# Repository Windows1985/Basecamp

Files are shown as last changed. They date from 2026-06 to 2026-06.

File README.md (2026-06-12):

# Basecamp

Basecamp is a passive overnight sleep monitoring system that runs on a Raspberry Pi 4 sitting on a bedside table. It combines WiFi channel state information from two ESP32-S3 nodes, 24GHz mmWave radar, an I2S microphone, and four environmental sensors to estimate sleep quality and produce a personalised recovery score each morning. Nothing touches the body. The system was built to answer a specific question: whether next-day cognitive performance is predictable from raw radio and acoustic signals, and which overnight conditions matter most for a specific person's physiology.

Three sensing modalities work in parallel during the night. Two ESP32-S3 nodes, one on each side of the bed at mattress height, measure how the body disturbs ambient WiFi signals across 56 subcarriers; chest movement during breathing creates measurable phase shifts that the system extracts via bandpass FFT in 30-second windows. A HLK-LD2410C 24GHz mmWave radar tracks bed entry, bed exit, and micro-motion throughout the night but does not output a respiration waveform, so breathing rate comes from CSI and audio only. An INMP441 I2S microphone captures breathing sounds and snoring, and four I2C environmental sensors monitor CO2, VOC, temperature, humidity, and light. The modalities were chosen because they are complementary: CSI measures fine respiratory displacement, radar provides reliable bed presence detection, audio catches acoustic breathing signatures, and environmental sensors capture conditions that affect sleep quality independently of body physiology.

The goal is a personalised recovery model, not a replacement for clinical sleep study. Sleep staging accuracy is approximately 72 to 78 percent across three classes, which is honest rather than competitive with polysomnography. Heart rate from CSI is trend-level and not reliable enough for HRV derivation. What the system does well is measure breathing rate more directly than wrist-based wearables (which infer it from optical heart rate), build a model calibrated to one person's physiology rather than population averages, and run continuously without any contact with the body.

## Hardware

The main components are listed below. See `hardware/bom.md` for the full bill of materials with prices and purchasing notes.

| Component | Quantity | Notes |
|---|---|---|
| Raspberry Pi 4 Model B | 1 | 4GB RAM; runs all daemons and the morning pipeline |
| ESP32-S3-DevKitC-1 N16R8 | 2 | One node each side of the bed at mattress height |
| SanDisk MicroSD 32GB | 1 | Class 10; all data stored locally in SQLite |
| INMP441 | 1 | I2S digital microphone; connected to GPIO 18, 19, 20 |
| HLK-LD2410C | 1 | 24GHz mmWave radar; UART at 256000 baud on hardware UART |
| SHT40 | 1 | Temperature and humidity; I2C address 0x44 |
| BH1750 | 1 | Light sensor; I2C address 0x23 |
| SCD40 | 1 | CO2 sensor; I2C address 0x62; verify chip markings before use |
| SGP40 | 1 | VOC index sensor; I2C address 0x59 |
| 2.8 inch IPS SPI touchscreen | 1 | ILI9341 or ST7789 driver, 240x320 pixels |
| DS3231 RTC module | 1 | Battery-backed real-time clock; maintains timestamps during offline power cycles |

The enclosure is 3D printed in matte black PLA at 96 x 136 x 49mm assembled (pod peak 74mm). The v4 magnetic-lid design lifts off tool-free for daily access; two M3x45 travel screws thread through the rear posts for transport only. Both ESP32 nodes power directly from the Pi's rear USB-A ports (no hub required). Networking uses a hotspot-first architecture: wlan0 runs as an isolated AP for the ESP32 nodes (the WiFi link exists solely because CSI is a property of a WiFi association), and eth0 provides internet and dashboard access. See `hardware/wiring.md` for GPIO assignments, `hardware/bom.md` for the complete component list, and `docs/networking.md` for the wlan0/eth0 architecture.

## Architecture

Three lightweight daemons run overnight on the Pi. The sensor logger reads all I2C environmental sensors every 30 seconds and writes to SQLite. The presence watcher monitors the radar, writes bed entry and exit timestamps, and fires the morning batch job when bed exit is detected after a minimum four-hour sleep duration. The audio chunker processes microphone input in 30-second chunks, classifying each as silence, ambient, or snoring, and stores relevant chunks as Opus files. A separate CSI ingest process receives raw CSI over UDP from the ESP32 nodes and writes cross-subcarrier variance to the database at 20 Hz. Nothing runs during the night beyond lightweight logging; all analysis runs in the morning.

```
hardware/       bill of materials, wiring reference, enclosure STL
firmware/       ESP32 flashing scripts and CSI capture configuration
server/         overnight daemons: sensor logger, presence watcher, audio chunker, sleep mode state machine
pipeline/       morning batch: CSI extraction, feature engineering, staging, scoring, attribution, anomaly detection, report
dashboard/      React web app for sleep and recovery visualisation
morning/        Flask API for daily subjective log (recovery, energy, clarity, mood ratings)
analysis/       Jupyter notebooks for MESA transfer learning and model evaluation
docs/adr/       architecture decision records for every major design choice
docs/build-log/ weekly entries covering what was built, what changed, and what failed
```

## Signal processing

The CSI breathing rate extraction treats the cross-subcarrier variance signal from each ESP32 node as a 20 Hz time series. For each 30-second window (600 samples), the pipeline applies a 4th-order Butterworth bandpass filter from 0.10 to 0.50 Hz, which corresponds to 6 to 30 breaths per minute and covers the full physiological range for sleeping adults. The dominant frequency within that band is extracted via an 8192-point zero-padded FFT, giving a frequency resolution of 0.0024 Hz, which is approximately 0.06 BPM. In synthetic testing against known ground-truth signals, the extraction achieves around plus or minus 0.06 BPM accuracy. Real-world accuracy depends on signal quality, mattress thickness, and sleeping position, and has not yet been measured on real overnight data. Movement power is extracted from the same signal using a complementary high-pass filter above 0.50 Hz.

## Sleep staging

The sleep stage classifier produces three classes: wake, deep sleep, and a combined light and REM class. N1 and N2 are not distinguished because the respiratory and motion differences between them are not detectable from radio or acoustic signals without EEG; any system claiming to separate N1 from N2 using WiFi CSI alone is overclaiming. Wake is detected by movement power above threshold from radar and CSI combined. Deep sleep is characterised by sustained low movement, slow and regular breathing in the 10 to 15 BPM range, and long uninterrupted windows. REM is estimated probabilistically within the light and REM class via breathing irregularity and snoring detection, and is stored as a flag rather than a separate stage. Expected accuracy is around 88 percent for wake, 75 percent for deep sleep, and 65 percent for the combined light and REM class, for an overall three-class accuracy of approximately 72 to 78 percent. These estimates come from the published literature on similar sensor configurations and should be treated as approximate until measured on real data. A Random Forest personalisation layer activates after 14 nights and is trained on heuristic labels, not EEG ground truth. A planned Phase 3 upgrade will pretrain on the MESA Sleep dataset (actigraphy plus PSG annotations) and fine-tune on personal data, which published work suggests improves three-class accuracy by 5 to 8 percentage points.

## Recovery score

The morning recovery score is a weighted composite across four components.

| Component | Weight | What it measures |
|---|---|---|
| Sleep architecture | 40% | Deep sleep proportion, REM estimate, total duration, and sleep efficiency |
| Continuity | 25% | Awakening count, sleep onset latency, and fragmentation |
| Breathing quality | 20% | Breathing regularity, snoring duration, and estimated apnea events |
| Environment | 15% | Peak CO2, VOC index, temperature deviation from optimal, and light intrusion |

The fixed weights reflect published sleep science on which factors most reliably predict next-day cognitive performance. After approximately 30 labelled nights, a regression model replaces the fixed scoring formula and learns weights specific to one person's physiology, using morning ratings across four subjective dimensions: recovery, energy, mental clarity, and mood. SHAP attribution then generates a plain-language explanation of each night's result, identifying which factors drove the score up or down.

## Known limitations

- Concrete walls between the ESP32 nodes and the bed will substantially degrade CSI signal quality; both nodes must be in the same room as the sleep area.
- Heart rate variability cannot be derived from CSI at the accuracy needed for HRV analysis; the system does not attempt HRV measurement.
- No SpO2 measurement is included; oxygen saturation monitoring requires a contact sensor.
- Sleep staging accuracy is limited by the absence of EEG ground truth; the three-class classifier is trained on heuristic labels, not PSG-validated annotations.
- Heart rate from CSI is trend-level only and is not reported as a precise per-beat measurement.
- The Pi's single radio chip cannot simultaneously run as an AP (for the ESP32 nodes) and a station client; internet access requires eth0.
- The personalised recovery predictor requires a minimum of 14 labelled nights before the machine learning layer activates; the fixed-weight model runs until then.
- The SGP40 VOC sensor requires approximately 24 hours of burn-in before its readings are reliable.

## Status

The software pipeline is complete and tested against simulated data. Hardware assembly and first real-world data collection have not yet started. All pipeline unit tests pass with simulated sensor data. No real sleep data has been collected.

## Acknowledgements

Sleep staging transfer learning uses the MESA Sleep dataset from the National Sleep Research Resource. Required acknowledgement: "NSRR R24 HL114473: NHLBI National Sleep Research Resource."

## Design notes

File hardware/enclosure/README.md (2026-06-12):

# Enclosure v4

Parametric CadQuery generator for the Basecamp bedside enclosure. Two-part matte black FDM print: body and lid.

**Final dimensions:** 96 x 136 x 49mm assembled, screen pod peak 74mm.

---

## Files

| File | Description |
|---|---|
| `enclosure_v4.py` | Parametric source of truth. All geometry driven by named constants at the top of the file. Edit here, never in the STEP/STL exports. |
| `basecamp_body_v4.step` | Body STEP for SolidWorks import or direct slicing |
| `basecamp_lid_v4.step` | Lid STEP |
| `basecamp_body_v4.stl` | Body STL for direct upload to print service |
| `basecamp_lid_v4.stl` | Lid STL |
| `validate.py` | Collision and watertightness test suite. Run after any geometry change. |
| `previews/` | Render images: body, lid, assembled (3 views each), 2D cross-sections |
| `archive/v3/` | v3 files retained for the build-log narrative |

---

## Generating the STL/STEP exports

```bash
pip install cadquery
python enclosure_v4.py
# Outputs: basecamp_body_v4.step/.stl, basecamp_lid_v4.step/.stl
```

Run validate.py afterward before sending to the printer:

```bash
pip install trimesh manifold3d
python validate.py
# All checks should print OK
```

---

## Print settings

### Body

- Orientation: flat on the base (no supports needed)
- Layer height: 0.2mm
- Infill: 20% gyroid
- Perimeters: 3 (ensures walls are solid at 3mm)
- Material: matte black PLA or PETG

### Lid

- Orientation: top face down on the build plate
- Supports: required under registration lip, boss columns, and pod interior cavity
- Layer height: 0.15mm for the pod slope (0.2mm acceptable elsewhere)
- Infill: 20% gyroid
- Perimeters: 3
- Material: same material as body -- thermal expansion must match

### Clearances

The design assumes 0.3-0.4mm FDM tolerance. Key mating features:

| Feature | Clearance |
|---|---|
| Registration lip (body seat to lid lip) | 0.25mm per side |
| Chimney plug (lid plug to chimney walls) | 0.40mm per side |
| Magnet boss pocket (body-side recess) | 0.1mm per side |

If the lip binds after printing: sand the outer face of the lid lip with 400-grit, test fit, repeat. Do not sand the body seat.

---

## Magnet assembly procedure

The lid is held by 6 pairs of O6x3 N35 magnets (2 front, 2 rear, 2 mid-side). Body-side magnets sit recessed 0.8mm in wall-boss pockets; lid-side magnets glue in proud 0.8mm so the faces meet flush when the lid seats.

**CHECK POLARITY BEFORE GLUING.**

1. Dry-stack all 12 magnets into their intended pockets without glue.
2. Close the lid and verify it seats and releases cleanly.
3. Open the lid carefully without disturbing the magnets.
4. Mark the same face of each magnet (the face pointing away from the body wall) with a permanent marker.
5. Remove magnets one at a time, apply a small drop of CA glue or epoxy to the pocket, and replace each magnet mark-up on the body side and mark-down on the lid side.
6. Hold each pair in place for 30 seconds before moving to the next.
7. Allow full cure (CA: 5 minutes; epoxy: per package) before closing the lid.

Polarity error means two magnets repel instead of attract. If a pair repels after gluing, the magnet must be drilled out and replaced -- there is no non-destructive fix.

---

## Travel screws

Two M3x45 pan-head screws thread upward through the two rear hollow posts for transport (HK to Shenzhen to California relocations). Install only before travel; remove after arrival. Screw heads sit in counterbores under the base covered by rubber feet. The front posts were deleted in v4; only the two rear posts accept screws.

To install: remove the two rear rubber feet, drive M3x45 from below through the post bores, tighten to finger-tight plus a quarter turn. Replace feet over the counterbores after arrival.

---

## Assembly order

1. Mount Pi 4 on the four floor standoffs (M2.5 x 5mm). GPIO edge faces right (toward chimney), USB-C power port faces left.
2. Cable the Pi: right-angle USB-C adapter plugs into the Pi's USB-C port and exits through the left wall power slot (zero internal routing). Ethernet exits through the rear IO cutout.
3. Mount ESP32 nodes on their floor rails. Node 1 short USB-A-to-C cable (25cm) plugs directly into a rear Pi USB-A port. Node 2's 5m 20AWG USB-A-to-C cable plugs into the other rear Pi USB-A port and exits through the IO cutout.
4. Press SCD40 into the chimney card slot (foam wedge or Blu-Tack to hold it). Route wires through the grommet. Do this before flipping the box.
5. Mount SHT40 and SGP40 on the accessory boss grid (M2 self-tap, right side sensor zone floor).
6. Mount BH1750 under the lid light hole position, aligned to the countersink.
7. Mount INMP441 behind the mic funnel recess. The O6->O2.5 waveguide locates it; foam tape to secure.
8. Mount DS3231 RTC module on the I2C bus (address 0x68). Confirm CR2032 battery is installed before closing the lid.
9. Install RGB glow LED in the O3 hole in the lid, in front of the pod. Connect to GPIO pins defined in config.py.
10. Flip box. Drive 2x M3x45 pan-head from below through the rear posts only. Torque to finger-tight plus a quarter turn. Stick O12mm adhesive rubber feet over the counterbores (2 rear posts + 2 front corners inboard).
11. Slide screen module forward onto the rails until it stops against the front wall. Glass sits 0.7mm below the outer face. Apply a single strip of tape across the rear edge (anti-rattle only). Connect ribbon cable before inserting.
12. Close lid. Listen for the magnetic click at all six points. The registration lip aligns the parts; magnets provide the closing force. Travel screws are NOT installed unless transporting.

SD card is accessible through the 8mm gap under the baffle without removing the lid.

---

## Ventilation (v4)

Intake air enters through base slots (sensor-zone floor slots and chimney floor slot), hidden by the foot gap. Chimney exhaust exits through the rear wall. The sensor zone vents through the under-baffle gap into the compute zone and out the rear IO opening. Pi warmth drives a continuous room->sensor->compute->out flow; air never flows compute->sensor, so sensor-zone readings are upstream of all heat sources except the ESP32 nodes.

Left wall has only the ESP32 USB service slot and the Pi power slot. Right wall is blank.

---

## Geometry reference

Key internal coordinates (X = width, Y = length, Z = up from floor):

| Feature | Position |
|---|---|
| Inner cavity | X +-45, Y +-65, Z 3-46 |
| Baffle (sensor/compute split) | Y -29 (front face), 8mm cable gap at floor |
| Pi PCB footprint | X -28..28, Y -20..65, ports flush with inner rear wall |
| Pi standoffs | (+-24.5, -18.5), (+-24.5, 39.5) |
| Rear IO cutout | 58mm wide, Z 8-27 |
| ESP32 rails | X -38..18, Y -57.5..-29.5 |
| USB service slot (left wall) | Y -57.5, Z 5-14 |
| Pi power slot (left wall) | beside USB-C port, Z 5-14 |
| Chimney interior | X -45..-29, Y 30..65 |
| SCD40 card slot ribs | X -38..-33.8, Y 36..54 |
| Grommet | left chimney wall, Y 45, Z 13 |
| Rear corner posts (travel screws) | (+-40.7, -61.35), O6.5 |
| Screen pod Y span | Y -22..36 (low edge front, faces bed) |
| BH1750 countersink | lid, sensor zone |
| Mic funnel | front wall, O6->O2.5 waveguide |
| Recovery glow LED hole | lid, O3, in front of pod |
| Condensation drain | front wall, O2, at floor level |
| Magnet bosses (body) | 2 front wall, 2 rear wall, 2 mid side walls |

See `hardware/bom.md` for the full component BOM.

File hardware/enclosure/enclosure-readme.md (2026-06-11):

# Enclosure

Parametric CadQuery generator for the Basecamp bedside enclosure. Two-part matte black FDM print: body and lid.

**Final dimensions:** 96 x 136 x 54mm assembled, screen pod peak 79mm.

---

## Files

| File | Description |
|---|---|
| `enclosure_v3.py` | Parametric source of truth. All geometry is driven by named constants at the top of the file. Edit here, never in the STEP/STL exports. |
| `basecamp_body_v3.step` | Body STEP for SolidWorks import or direct slicing |
| `basecamp_lid_v3.step` | Lid STEP |
| `basecamp_body_v3.stl` | Body STL for direct upload to print service |
| `basecamp_lid_v3.stl` | Lid STL |
| `validate.py` | Collision and watertightness test suite. Run after any geometry change. |
| `previews/` | Render images: body, lid, assembled (3 views each), 2D cross-sections |

---

## Generating the STL/STEP exports

```bash
pip install cadquery
python enclosure_v3.py
# Outputs: basecamp_body_v3.step/.stl, basecamp_lid_v3.step/.stl
```

Running validate.py afterward is strongly recommended before sending to the printer:

```bash
pip install trimesh manifold3d
python validate.py
# All checks should print OK
```

---

## Print settings

### Body

- Orientation: flat on the base (no supports needed)
- Layer height: 0.2mm
- Infill: 20% gyroid
- Perimeters: 3 (ensures walls are solid at 3mm)
- Material: matte black PLA or PETG

### Lid

- Orientation: top face down on the build plate
- Supports: required under registration lip, boss columns, and pod interior cavity
- Layer height: 0.15mm for the pod slope (0.2mm acceptable elsewhere)
- Infill: 20% gyroid
- Perimeters: 3
- Material: same material as body -- thermal expansion must match

### Clearances

The design assumes 0.3-0.4mm FDM tolerance. Key mating features:

| Feature | Clearance |
|---|---|
| Registration lip (body seat to lid lip) | 0.25mm per side |
| Chimney plug (lid plug to chimney walls) | 0.40mm per side |
| M3 bore through posts | 3.4mm (M3 thread-forming, no insert needed) |

If the lip binds after printing: sand the outer face of the lid lip with 400-grit, test fit, repeat. Do not sand the body seat.

---

## Assembly order

1. Mount Pi 4 on the four floor standoffs (M2.5 x 5mm). GPIO edge faces right (toward chimney), power/HDMI edge faces left.
2. Cable the Pi: right-angle USB-C adapter for power (exits through rear slot), ethernet through rear slot, any GPIO breakout through the Ø8 grommet in the chimney right wall.
3. Mount ESP32 nodes on their floor rails. USB-C service port aligns with the left wall slot.
4. Place the powered USB hub on edge in the right margin (max 85 x 30 x 15mm). Route hub power cable through rear slot.
5. Press SCD40 into the chimney card slot (foam wedge or Blu-Tack to hold it). Route wires through the grommet. Do this before flipping the box, or the SCD40 will fall out.
6. Mount SHT40 and SGP40 on the accessory boss grid (M2 self-tap, right side sensor zone floor).
7. Mount BH1750 under the lid light hole position (foam tape, align to Ø6mm hole).
8. Mount INMP441 behind the mic alignment recess (front face, left side). The 16 x 13mm recess locates it; foam tape to secure.
9. Flip box, drive 4x M3x50 pan-head from below. Torque to finger-tight plus a quarter turn. Stick Ø12mm adhesive rubber feet over the counterbores (4x, inboard of the posts).
10. Slide screen module forward until the front edge seats against the front pod wall (this is the alignment stop). Foam tape or VHB to the pod floor. Connect ribbon cable before inserting.
11. Set lid on body, check registration lip seats evenly all the way around.

SD card is accessible through the 8mm gap under the baffle without removing the lid.

---

## Sensor notes

**CO2 lag:** The SCD40 chimney equilibrates by diffusion plus passive stack effect. Expect 5-15 minutes of lag behind room CO2 changes. This is acceptable for overnight trend logging; the slow drift of room CO2 during sleep is the signal of interest, not step changes.

**Temperature offset:** The sensor zone will run approximately 0.5-1 degC above ambient due to ESP32 and general enclosure warmth. The offset is stable. Calibrate against a reference thermometer on the first night and record the offset. The adaptive threshold system absorbs a stable bias; what matters is consistency, not absolute accuracy.

**Radar and antenna membranes:** The front face uses 1mm PLA membranes over the HLK-LD2410C radar aperture (24 x 17mm) and the ESP32 antenna window (18 x 14mm). PLA at 1mm is effectively transparent at 2.4GHz and 24GHz. Do not remove the membranes to "improve signal" -- they protect the sensors and the open-hole aesthetics are worse.

---

## BOM additions (enclosure-specific)

| Item | Qty | Notes |
|---|-----|---|
| M3 x 50mm pan-head black | 4 | Thread-forming into 3.4mm bore, no insert |
| Right-angle USB-C adapter | 1 | Required for Pi power, left wall clearance |
| Ø12mm adhesive rubber feet | 4 | Placed inboard of corner posts |
| VHB tape or foam tape | 1 sheet | Screen module and sensor mounting |
| Ø8mm cable grommet | 1 | Pre-installed in chimney right wall |
| Pi 4 heatsink | 1 | Compute zone ventilates through rear IO opening |

See `hardware/bom.md` for the full component BOM.

---

## Geometry reference

Key internal coordinates (X = width, Y = length, Z = up from floor):

| Feature | Position |
|---|---|
| Inner cavity | X +-45, Y +-65, Z 3-51 |
| Baffle (sensor/compute split) | Y -29 (front face), 8mm cable gap at floor |
| Pi PCB footprint | X -28..28, Y -20..65, ports flush with inner rear wall |
| Pi standoffs | (+-24.5, -18.5), (+-24.5, 39.5) |
| Rear IO cutout | 58mm wide, Z 8-27 |
| ESP32 rails | X -38..18, Y -57.5..-29.5 |
| USB-C service slot | left wall, Y -57.5, Z 5-14 |
| Chimney interior | X -45..-29, Y 30..65 |
| SCD40 card slot ribs | X -38..-33.8, Y 36..54 |
| Grommet | left chimney wall, Y 45, Z 13 |
| Corner posts | (+-40.7, +-61.35), Ø6.5, top Z 41 |
| Screen pod Y span | Y -22..36 (low edge front, faces bed) |
| BH1750 light hole | X -25, Y -45 (lid, Ø6mm) |

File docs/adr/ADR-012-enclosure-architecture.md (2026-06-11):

# ADR-011: Enclosure Architecture

**Date:** 2026-06-11
**Status:** Accepted

---

## Context

The Basecamp enclosure needs to house a Raspberry Pi 4, two ESP32-S3 nodes, six environmental sensors, a 2.8" ILI9341 touchscreen, a powered USB hub, and all associated cabling in a bedside form factor. It must be printable on a standard FDM service, assembleable by one person without specialist tools, and presentable enough to be left on a bedside table indefinitely.

Several competing constraints shaped the design:

- No fan permitted: a fan introduces a constant noise floor directly beside the INMP441 microphone, corrupting the acoustic sensing channel.
- Screen must be readable from bed without the user sitting up.
- All sensors must measure room air, not enclosure-modified air, so thermal isolation from the Pi compute zone is required.
- The SCD40 CO2 sensor requires access to ambient air but cannot be left in an open cavity (RH condensation risk, and it needs a stable micro-environment).
- The Pi 4's USB/Ethernet ports must remain accessible for initial setup and SD card access in the field.
- The enclosure will be printed at a Taobao service in Hong Kong and must arrive print-ready.

---

## Options Considered

### Fastener style

**Option A: Top-entry M3 screws with visible heads.**
Simple to assemble, standard practice for project enclosures. Rejected: visible screw heads on the top face break the Apple aesthetic goal and create snagging points.

**Option B: Side-clip lid.**
No fasteners visible from any angle. Rejected: clips require tight dimensional tolerances that FDM printing does not reliably achieve, and the lid would flex and pop under lateral pressure from a cable catch.

**Option C: Bottom-entry M3x50 through hollow corner posts, heads hidden under adhesive feet.**
Chosen. Zero visible fasteners from any angle. The post geometry (Ø6.5, 41mm tall) is printable in-place, and the screw pattern (4x at ±40.7, ±61.35) gives a registration force that pulls the lid lip evenly into the body seat. M3x50 pan-heads sit flush in counterbores under the base; feet are placed inboard of the posts rather than over them.

### Screen orientation

**Option A: Screen facing away from bed (toward the room).**
Avoids light pollution during sleep. Rejected: requires the user to get up to read recovery scores, defeating the main UX goal of a score readable on waking.

**Option B: Screen facing the bed.**
Chosen, on the condition that the backlight is off during sleep. `screen.py` implements GPIO22 backlight control, keeping the display dark until the user taps to activate. With this in place there is no light-hygiene argument for facing the screen away. The pod low-edge sits at the front (bed side), tilting the display at 19 degrees toward the user.

### SCD40 housing

**Option A: Open hole in sensor zone wall.**
Simple. Rejected: condensation ingress risk and no physical protection for the fragile SCD40 carrier board.

**Option B: Fully sealed chimney box with lid fixed in place.**
Reviewed and found to be a build blocker: a fully sealed chimney makes the sensor uninstallable and provides no wire path to the Pi GPIO header.

**Option C: Chimney with open top (body walls stop below lid), lid-mounted plug cap (labyrinth seal), Ø8 grommet for wiring, and card-slot ribs for the SCD40 PCB.**
Chosen. The chimney occupies the left-rear dead zone beside the Pi (interior 14 x 33.5mm), using two body walls and two added walls. The lid plug drops 4mm into the chimney opening with 0.4mm clearance, forming a labyrinth seal that blocks bulk airflow while allowing the sensor to equilibrate. Low intake vents (z 8, 12) and high exhaust vents (z 40, 44) on the left wall drive passive stack-effect ventilation. The grommet routes SCD40 wiring directly to the Pi GPIO edge without entering the main cavity.

### Apertures for radar and ESP32 antenna

**Option A: Open windows.**
Maximises RF transparency. Rejected: open holes collect dust, break the front face aesthetics, and create a direct acoustic path into the mic cavity.

**Option B: 1mm PLA membrane.**
Chosen. PLA at 1mm is effectively RF-transparent at 2.4GHz and 24GHz (skin depth >> wall thickness). The front face has zero open holes except the 2.5mm mic port with its alignment recess. The radar pocket (24 x 17mm) and ESP32 antenna window (18 x 14mm) both sit behind flush membrane surfaces.

---

## Decision

96 x 136 x 54mm assembled body + lid, pod peak 79mm. Matte black FDM print, two-part body/lid split. Specific dimensions driven by:

- Width (96mm): 86mm ILI9341 screen module + 2.2mm pod wall each side + 2mm reveal.
- Length (136mm): 38mm sensor zone + 3mm baffle + 95mm compute zone (85mm Pi PCB + 4mm front gap + 3mm rear wall).
- Height (54mm): Pi 4 USB-A stack (25.4mm) + 5mm standoff + 3mm floor + headroom; hub stands on edge in the 17mm right margin beside the Pi.

Zero visible fasteners (bottom-entry M3x50). Screen pod faces bed at 19 degrees, activated by tap via GPIO22. SCD40 in left-rear chimney with labyrinth plug seal. All apertures behind 1mm membranes except the mic port. 1.8 x 2.5mm registration lip for a repeatable lid seam.

---

## Consequences

**Positive:**
- Passes boolean collision validation: lid-on-body intersection volume 0.0mm3; all component envelopes (Pi, ESP32, hub, SCD40, screen module) clear both parts.
- Both parts watertight (trimesh). Body prints support-free; lid prints top-face-up with supports under lip, bosses, and pod interior.
- 35% volume reduction vs the v2 concept (156cm3 vs 241cm3), lower print cost and mass.
- Screen readable from bed without sitting up.
- SCD40 serviceable by lifting lid; SD card reachable through the 8mm under-baffle gap.

**Constraints introduced:**
- Hub must be <=85 x 30 x 15mm to fit on edge in the right margin. Verify dimensions against Taobao listing before ordering.
- Right-angle USB-C adapter required for the Pi power input to avoid the cable fouling the left wall.
- Screen module assembly: slide module forward until it seats against the front wall stop, then foam-tape. Do not tape before positioning -- the pod is a sloped cavity and the module must seat on the slope, not hang in the air.
- 0.3-0.4mm clearances on lip and chimney plug assume a calibrated FDM printer. If the print service runs hot, the lip may bind; a light pass with 400-grit sandpaper on the mating face resolves this.
- Temp/humidity readings will show a stable warm bias of approximately +0.5 to +1 degC from ESP32 and general enclosure warmth. Calibrate against a reference on the first night; the adaptive threshold system absorbs a stable offset.

**Validated by:**
`hardware/enclosure/validate.py` -- boolean intersection tests for lid-vs-body and all component envelopes, run against the STEP exports. Re-run this after any geometry edit before sending to the print service.

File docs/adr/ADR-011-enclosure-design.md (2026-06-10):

# ADR-011: Enclosure Design Decisions

**Date:** 2026-06-10
**Status:** Accepted

## Context

The enclosure was designed parametrically using CadQuery before hardware arrived, based on verified component dimensions. Three decisions deviated from the original spec during modelling.

## Decision 1: Compute zone depth is 101mm, not 60mm

The original spec stated a 40mm sensor zone + 60mm compute zone = 100mm internal length. This does not sum to the 144mm internal length of a 150mm outer box with 3mm walls. Additionally, the Pi 4 (85mm long) plus rear connector clearance (ethernet plug boot ~25mm) requires at least 95mm. The compute zone is derived as whatever remains after the sensor zone and baffle: approximately 101mm.

**Alternative considered:** Shrinking outer_L to ~110mm. Rejected — insufficient rear cable bend radius and USB hub has no home.

## Decision 2: Chimney relocated to right wall, self-capped

The original spec placed the SCD40 chimney venting through the lid. The screen pod (92mm wide, covering most of the lid) occupies the space above the sensor zone. The chimney was moved to the right wall with low intake and high exhaust slots, and given a solid cap at 66mm to prevent pod cavity air from bypassing the isolation. Convection path is functionally equivalent.

**Alternative considered:** Reducing pod width to preserve lid chimney. Rejected — pod must accommodate the full 86x50mm PCB, not just the 57.6x43.2mm active area.

## Decision 3: Screen pod sized to full PCB (86x50mm), not active area

The ILI9341 2.8" module PCB is 86x50x14.3mm (verified from datasheets). The original pod (66mm wide) was sized to the active display area only and would not have fit the module. Pod inner width is 87.6mm (1.6mm clearance).

## Decision 4: ESP32 node integrated with antenna window and USB service slot

Node 1 is integrated into the enclosure. The front face has an 18x12mm open antenna window aligned with the WROOM module's antenna end, placing no plastic in the CSI radiation path toward the bed. The left wall has a 22x9mm service slot aligned with the board's two USB-C ports, allowing flashing and provisioning without disassembly. Node 2 remains a satellite.

## Decision 5: Radar hidden behind 1mm membrane

The LD2410C radar is concealed behind a 1mm plastic membrane (inner pocket cut from 3mm wall). 24GHz signals penetrate thin PLA with negligible attenuation — this is standard practice for commercial mmWave products. Benefit: clean blank front face consistent with Apple-style design intent.

## Consequences

- `hardware/enclosure/enclosure_v2.py` is the canonical parametric source; edit variables and re-run to regenerate STEP files
- All aperture positions are derived from component dimensions verified against datasheets, not estimates
- Standoff positions match Pi 4 mounting hole pattern exactly (58x49mm, 3.5mm from edges)
- Rear I/O cutout raised to z=27mm to clear USB-A stack height above PCB
- If antenna window position needs adjustment (clone DevKit boards vary ±1-2mm), change `ANT_WIN_CX` in the script and reprint

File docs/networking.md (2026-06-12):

# Networking

Basecamp uses a split-radio architecture: wlan0 is an isolated AP for the ESP32 nodes only, and eth0 is a DHCP client for internet, NTP, and dashboard access.

---

## Why the WiFi network exists at all

CSI (channel state information) is a property of a WiFi link. There is no way to collect CSI without a working 802.11 association between the ESP32 nodes and an access point. The Pi's wlan0 AP is that access point. The network carries no general traffic -- only the UDP CSI stream from each ESP32 node to the Pi, and DHCP/DNS for the nodes themselves.

The AP runs on a fixed channel (channel 6, 20MHz bandwidth, N-only) so the RF environment is identical at every deployment location. This is what makes CSI baselines portable between HK, Shenzhen, and Cate without retraining.

---

## Interface roles

| Interface | Role |
|---|---|
| wlan0 | AP for ESP32 nodes only. SSID: Basecamp-Node. Fixed IP 192.168.4.1. No internet routing from this interface to the wider LAN. |
| eth0 | DHCP client. Internet, NTP, and dashboard access. Phone and laptop reach the dashboard here. |

The Pi has one radio (combo chip). It cannot be simultaneously an AP on wlan0 and a station client on a router's SSID. All internet access requires eth0.

---

## Reaching the dashboard by location

**Home (ethernet connected):**
- Pi's eth0 gets a LAN IP from the home router.
- Phone on the same LAN opens `http://basecamp.local:5000` or the Pi's LAN IP.

**Cate School (dorm room, ethernet connected):**
- Same as home: eth0 on the school LAN, dashboard accessible from any device on the same LAN segment.
- ESP32 nodes connect to Basecamp-Node (wlan0); they do not need internet access.

**No ethernet available:**
- Join the Pi hotspot (SSID: Basecamp-Node) on the phone.
- Dashboard accessible at `http://192.168.4.1:5000`.
- Note: the phone will have no internet while on this hotspot (the AP is isolated).

---

## NTP and timekeeping

NTP syncs over eth0 when available. The DS3231 RTC module (I2C 0x68) maintains time when eth0 is not connected. On power cycle without ethernet, the system clock is loaded from the RTC within seconds of boot -- no manual time-set needed.

If neither ethernet nor RTC is available (flat CR2032 battery), the Pi will boot with an incorrect time and session timestamps will be wrong. Replace the CR2032 battery immediately if `timedatectl` shows a clock far from the real time after an offline reboot.

---

## Bluetooth

Bluetooth is disabled (`dtoverlay=disable-bt` in config.txt). The Pi's BT radio shares the 2.4GHz band and the same combo chip as the CSI-serving AP. BT activity injects interference into the measured WiFi channel and time-slices the radio, corrupting CSI readings.

**Optional future experiment:** `rfkill block bluetooth` during measurement windows (23:00 to 08:00) without a permanent hardware change, to quantify the interference contribution. This would require a cron job or a systemd timer that calls rfkill on the measurement schedule.

---

## Deprecated: router-dependent setup

The original v1/v2/v3 setup used a dedicated 2.4GHz legacy SSID on an ASUS WiFi 7 router (SSID: RuView-24, N-only, 20MHz, MU-MIMO off). This required manual router configuration at every location, produced different RF environments at each site, and was incompatible with school network infrastructure.

The router-mode configuration is retained in the pi_setup.sh deprecated appendix in case a router is available and preferred. The hotspot setup in pi_setup.sh is the canonical path.

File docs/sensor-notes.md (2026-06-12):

# Sensor Notes

Calibration quirks, known offsets, and environmental effects for the Basecamp sensor suite.

---

## CO2 lag (SCD40)

The SCD40 chimney equilibrates by diffusion plus passive stack effect. Expect 5-15 minutes of lag behind room CO2 changes. This is acceptable for overnight trend logging; the slow drift of room CO2 during sleep is the signal of interest, not step changes.

The chimney uses low intake vents (base-level floor slots) and exhausts through the rear wall. The labyrinth-seal plug on the lid side blocks bulk airflow while allowing the sensor to equilibrate over the measurement timescale. Do not enlarge the chimney vents to speed up equilibration -- this would also increase RH variation and condensation risk for the fragile SCD40 PCB.

---

## Temperature offset calibration (SHT40)

The sensor zone runs approximately 0.5-1 degC above ambient due to ESP32 and general enclosure warmth. The offset is stable because the v4 ventilation architecture guarantees air flows room->sensor->compute->out, never compute->sensor (see Ventilation section below). The sensor-zone readings are upstream of the Pi heat source; only the two ESP32 nodes contribute warmth to the sensor zone.

Calibrate against a reference thermometer on the first night and record the offset in `server/config.py` as `TEMP_OFFSET_C`. The adaptive threshold system absorbs a stable bias; what matters is consistency, not absolute accuracy.

---

## SGP40 burn-in

The SGP40 VOC sensor requires approximately 24 hours of continuous operation before readings stabilise. The sensor runs a conditioning algorithm during this period. Do not log or act on VOC index values until the burn-in completes. The sensor logger marks readings as `pre_burnin = True` for the first 24 hours after first power-on.

---

## Screen rotation

The 2.8" ILI9341 display is mounted in the screen pod with the cable at the bottom. The pod tilts 19 degrees toward the bed. `SCREEN_ROTATION = 90` in `server/config.py` compensates for the physical rotation of the PCB within the pod. Change this constant (valid values: 0, 90, 180, 270) if the display orientation is incorrect after assembly; do not edit the rendering code directly.

---

## Air purifier interference

If a HEPA air purifier runs in the room, it will reduce CO2 variation (the purifier recirculates air but does not change CO2 levels -- this is fine) and may introduce acoustic noise in the 60-500 Hz band that overlaps with snore detection. If the purifier is running, check the snore detection threshold; you may need to raise `SNORE_THRESHOLD` in `server/config.py` to avoid false positives.

---

## Ventilation (v4 architecture)

v4 moved ventilation intake from the side walls to the base, and chimney exhaust from the top to the rear wall. The resulting airflow path is:

```
room air -> base intake slots -> sensor zone -> under-baffle gap -> compute zone -> rear IO opening
```

Pi warmth drives this flow via natural convection: the Pi heats the compute zone, which draws cooler air from the sensor zone, which draws fresh room air through the base intakes. The direction is guaranteed because the Pi (the largest heat source) sits at the downstream end of the path.

**What this means for sensor readings:**

- Temperature and humidity readings from SHT40 represent upstream (pre-Pi) room air. They are not contaminated by Pi heat.
- CO2 readings from the SCD40 chimney also sample upstream air; the chimney has its own dedicated base floor slot.
- VOC readings from SGP40 may capture a small contribution from ESP32 node outgassing, but this is a stable bias that calibrates out.

Left and right walls are blank in v4 (left wall has only the ESP32 USB service slot and the Pi power slot; right wall is blank). This eliminates side-wall cross-drafts that could disrupt the vertical convection path.

---

## DS3231 RTC and timestamps

The Pi 4 has no battery-backed real-time clock. Without the DS3231, an offline Pi loses time on every power cycle. Corrupted timestamps break session attribution (the morning pipeline uses bed-exit time to identify which overnight session to process) and make multi-night trend analysis unreliable.

The DS3231 provides hardware-backed time that survives offline power cycles. It is enabled by `dtoverlay=i2c-rtc,ds3231` in `/boot/config.txt` and sits on I2C address 0x68.

**fake-hwclock must be disabled.** The fake-hwclock service saves the system clock to a file on shutdown and restores it on boot, but it will overwrite the DS3231 time if both are active. Disable it:

```bash
sudo systemctl disable fake-hwclock
sudo systemctl stop fake-hwclock
```

After disabling fake-hwclock, verify the RTC is providing correct time after an offline reboot:

```bash
sudo hwclock -r       # read RTC time directly
timedatectl           # confirm system clock matches
```

If the RTC time drifts more than a few minutes per week, the CR2032 battery may be low. Replace it; the DS3231 draws microamps from the battery and a CR2032 should last several years.

---

## Radar and antenna membranes

The front face uses 1mm PLA membranes over the HLK-LD2410C radar aperture (24 x 17mm) and the ESP32 antenna window (18 x 14mm). PLA at 1mm is effectively transparent at 2.4GHz and 24GHz. Do not remove the membranes to "improve signal" -- they protect the sensors and the open-hole aesthetics are worse.

---

## INMP441 mic funnel

The v4 enclosure adds a O6->O2.5 waveguide in the front wall behind the INMP441 mounting position. The funnel maintains acoustic directionality toward the bed while reducing susceptibility to near-field noise from the enclosure interior. Mount the INMP441 flush against the funnel opening; foam tape secures the rear face.

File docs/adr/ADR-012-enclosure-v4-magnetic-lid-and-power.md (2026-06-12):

# ADR-012: Enclosure v4 - Magnetic Lid, Hub Deletion, and Hotspot Networking

**Date:** 2026-06-12
**Status:** Accepted

---

## Context

The v3 enclosure used four M3x50 screws to close the lid, a powered USB hub to supply the ESP32 nodes, and a home router with a legacy 2.4GHz SSID to provide the WiFi network the nodes need for CSI. Three problems emerged during planning for the HK/Shenzhen data-collection sprint:

- The sprint requires dozens of lid removals to service sensors and swap SD cards. Four screws and a screwdriver for every removal is impractical at that frequency.
- The powered hub added 10mm to the body height, requires a second wall outlet, and is a single-point failure in a system that already has many power rails.
- The ASUS WiFi 7 router SSID configuration is location-specific, meaning the CSI RF environment changes between HK, Shenzhen, and Cate, making session-to-session baselines incomparable.

---

## Options Considered

### Decision 1: Lid fastener method

**Option A: Four M3x50 screws (existing v3 design).**
Reliable and proven. Rejected for daily use: requires a screwdriver for every access during the sprint. Dozens of lid removals is the expected workload, not an edge case.

**Option B: Snap clips.**
Tool-free. Rejected: FDM snap clips require tight dimensional tolerances that service bureaux do not reliably achieve; clips flex and pop under lateral stress from cable catches.

**Option C: Magnetic lid with travel screws.**
Chosen. Six N35 magnet pairs (2 front, 2 rear, 2 mid-side) hold the lid for daily access; the registration lip still aligns the parts precisely. Two M3x45 travel screws thread through the rear posts and are installed only for the three relocations (HK to Shenzhen to Cate). This separates the daily-access mechanism from the transport-locking mechanism. Body height drops 51->46mm as a side effect of deleting the hub (which was the height driver); screws shorten from 50mm to 45mm.

**Consequences of Option C:**
- Six N35 magnet pairs required (buy 20-pack for spares; polarity must be verified before gluing).
- Front corner posts deleted (also resolves ESP32 corner clearance constraint from v3).
- Two M3x45 travel screws retained, stored in the enclosure bag when not in use.
- Lid polarity error is non-recoverable without drilling; the assembly procedure requires a dry-stack polarity check before any glue is applied.

---

### Decision 2: ESP32 power source

**Option A: Powered USB hub (existing v3 design).**
Dedicated 5V supply for the nodes; handles any current transients independently. Rejected: adds 10mm to body height, requires a second wall plug, and introduces an additional failure point.

**Option B: Pi USB-A ports (direct).**
Chosen. Both nodes draw from the Pi's own USB-A ports. Combined peak is approximately 0.8A (two ESP32-S3 at WiFi TX burst), within the Pi 4's 1.2A USB budget. The official 5V/3A PSU covers total system draw (Pi ~600mA + nodes ~800mA peak = 1.4A, well within 3A).

Node 1 uses a short 25cm USB-A-to-C cable routed to the rear Pi USB-A. Node 2's 5m cable must be 20AWG or thicker; thinner wire (e.g. 28AWG) causes voltage drop at ESP32-S3 WiFi TX bursts that triggers brownout resets. 20AWG is a hard requirement, not a preference. Verify the listing specifies wire gauge before ordering.

**Consequences of Option B:**
- Hub deleted from BOM (saves approximately Y30, one wall plug, and 10mm height).
- Both rear cable slots deleted from enclosure; Node 2's 5m cable exits through the IO cutout alongside ethernet.
- A startup check in the sensor daemon logs a warning if `vcgencmd get_throttled` reports undervoltage, since both nodes now share the Pi's supply.
- NODE2_USB_POWER = True documents this configuration in config.py.

---

### Decision 3: WiFi networking architecture

**Option A: Router-dependent (existing v3 design).**
Pi connects to a dedicated 2.4GHz legacy SSID on the ASUS router. Works at home. Rejected as primary path: the SSID configuration is specific to the ASUS router and must be recreated at each location. Different routers mean different RF environments, so CSI baselines collected in HK cannot be compared to baselines collected at Cate without retraining. The ASUS WiFi 7 router also requires non-default settings (N-only, 20MHz, MU-MIMO off) that are not available on school network infrastructure.

**Option B: Pi hotspot as canonical setup.**
Chosen. wlan0 runs as an isolated access point for the ESP32 nodes only (fixed channel, 20MHz bandwidth, hidden or not per config). The WiFi network exists solely because CSI is a property of a WiFi link; no general internet traffic traverses it. eth0 is a DHCP client for internet, NTP, and dashboard access. Phone reaches the dashboard over the LAN via ethernet (home or Cate ethernet), or by joining the Pi hotspot when no ethernet is available.

This architecture produces an identical RF environment at every location: same Pi radio, same SSID, same channel, same two node MAC addresses. CSI baselines transfer between locations without retraining. It also eliminates the ASUS router configuration burden entirely.

**One-radio constraint:** The Pi 4 has a single combo radio chip (wlan0). It can operate as an AP or a station, not simultaneously both. Internet access requires eth0. The hotspot setup documented in pi_setup.sh configures NAT from wlan0 to eth0 to give the nodes internet access if needed (not required for CSI operation).

**NTP and timekeeping:** An offline Pi (no eth0) loses time on power cycles because the Pi 4 has no battery-backed real-time clock. Corrupted timestamps break session attribution and the morning pipeline. The DS3231 RTC module (I2C address 0x68, ~Y10) is added to the BOM and enabled via `dtoverlay=i2c-rtc,ds3231` in config.txt. fake-hwclock must be disabled; the DS3231 provides hardware-backed time that survives offline power cycles. This is a hard dependency of the hotspot-everywhere architecture.

**Consequences of Option B:**
- pi_setup.sh becomes the canonical setup script (merges former pi_setup_hotspot.sh). Router-mode instructions retained in a deprecated appendix.
- DS3231 RTC added to BOM and I2C bus (address 0x68; add to expected i2cdetect list).
- timedatectl check added to bring-up procedure to confirm the RTC is providing time offline.

---

### Bluetooth note

BT PAN was considered as an alternative phone-sync path and rejected. The Pi's Bluetooth radio shares the 2.4GHz band and the same combo chip as the CSI-serving AP. BT activity injects interference into the measured WiFi channel and time-slices the radio between AP and BT roles, both of which corrupt CSI readings. Bluetooth is disabled via `dtoverlay=disable-bt` in config.txt.

Optional future experiment: `rfkill block bluetooth` during measurement windows to verify the interference contribution without a permanent hardware change.

---

## Consequences

**Positive:**
- Body height 51mm -> 46mm (assembled 49mm, pod peak 74mm); smaller print, lower cost (~Y40).
- Tool-free daily lid access during the data-collection sprint.
- Identical RF environment across all deployment locations; CSI baselines transfer.
- One fewer wall plug; one fewer potential failure point.
- Offline timekeeping via DS3231 eliminates corrupted session timestamps.

**Constraints introduced:**
- Node 2 cable must be 20AWG or thicker; verify the listing before ordering.
- Magnet polarity must be checked before gluing; reversal is non-recoverable without drilling.
- Travel screws (2x M3x45) required before any relocation; keep them in the enclosure bag.
- DS3231 RTC required for correct offline operation; fake-hwclock must be disabled.
- Phone internet access requires eth0 or joining the Pi hotspot (no transparent bridging to the wider LAN via wlan0).

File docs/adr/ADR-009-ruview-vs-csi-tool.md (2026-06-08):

# ADR-009: RuView vs ESP32-CSI-Tool for CSI extraction

## Context
The WiFi CSI layer requires firmware on the ESP32 to capture channel state information and software on the Pi to process it. Two main options exist: RuView (complete end-to-end pipeline) and ESP32-CSI-Tool (raw CSI extraction only, requiring a custom processing layer).

## Options considered
- RuView: complete pipeline including firmware, Rust sensing server, signal processing, and pre-trained models
- ESP32-CSI-Tool: battle-tested CSI extraction only, custom Python processing layer built on top

## Decision
ESP32-CSI-Tool for firmware and a custom Python processing layer for all signal analysis. RuView is referenced as a prior art implementation only.

## Reasoning
RuView has a known bug in which the JSONL model file fails to load, causing the system to fall back silently to heuristic mode for sleep staging. The bug was confirmed unpatched as of the decision date. Silent fallback to a different algorithm with no user-visible indication is not acceptable for a system where trust in the output matters.

Beyond the bug, using RuView would make the processing pipeline opaque. Every layer of CSI processing in this project is code written and understood by the author. ESP32-CSI-Tool is battle-tested firmware for raw CSI extraction from ESP32 hardware. The custom Python layer in pipeline/csi.py applies a 4th-order Butterworth bandpass filter from 0.10 to 0.50 Hz, extracts the dominant frequency via an 8192-point zero-padded FFT, and computes movement power from the high-pass component. This pipeline is straightforward to debug and extend.

CSI frames are parsed using CSIKit where available, with a CSV fallback for frames logged by ESP32-CSI-Tool's serial output format. The two parsers produce identical output structures so the rest of the pipeline is unaffected by which parser handles a given frame.

In synthetic testing against known ground-truth breathing signals, the frequency extraction achieves approximately plus or minus 0.06 BPM accuracy. This figure has not yet been validated on real overnight data.

## Consequences
The firmware flashing procedure uses ESP32-CSI-Tool scripts in the firmware/ directory. The custom processing layer adds development time compared to using RuView out of the box, but every processing decision is visible and adjustable. Filter parameters were chosen based on published literature and will likely require tuning once real subcarrier data from the specific room geometry is available. CSIKit is listed in requirements as an optional dependency; the CSV fallback ensures the pipeline runs without it.

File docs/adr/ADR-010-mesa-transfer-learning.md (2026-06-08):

# ADR-010: MESA dataset for sleep staging transfer learning

## Context
The two-phase sleep stage classifier described in ADR-006 trains its Random Forest personalisation layer on heuristic labels generated by the same system it is trying to improve. Self-referential training on heuristic labels risks reinforcing systematic errors rather than correcting them: if the heuristic misclassifies certain breathing patterns as light sleep instead of deep, the model learns to reproduce that error. After enough nights the model may overfit to the individual's idiosyncrasies in a way that degrades generalisability and makes the score less interpretable.

The practical problem is that obtaining EEG-validated ground truth labels for a single person sleeping in their own bedroom is expensive and disruptive. PSG requires electrode attachment and laboratory conditions or a clinical visit. A wearable EEG headband is an option but adds contact with the body, which the system design explicitly avoids.

## Options considered

**Personal heuristic labels only.** The simplest approach: train the personalisation layer entirely on labels from the system's own heuristic classifier. No external data is needed. The limitation is that the labels the model learns from contain the same systematic errors the model is supposed to reduce. Accuracy plateaus wherever the heuristic is consistently wrong.

**Commercial wearable as supervision.** Use an Oura ring, WHOOP, or similar device to provide sleep stage labels for training. This introduces body contact, adds cost and daily behaviour change, and the wearable's own labels are population-model estimates rather than EEG ground truth. Trading one estimate for another does not solve the fundamental label quality problem.

**MESA transfer learning.** Pretrain on the MESA Sleep dataset (actigraphy features plus PSG-validated staging annotations), then fine-tune on personal nights. MESA provides EEG-validated labels for 2,056 participants at 30-second epochs. The pretrained model encodes a prior over what staging looks like based on movement and breathing features, reducing dependence on the quality of personal heuristic labels.

## Decision
MESA transfer learning, implemented as described in analysis/mesa_transfer.ipynb. Data access was approved under a Data Use Agreement with Brigham and Women's Hospital through the National Sleep Research Resource (NSRR).

## Reasoning
The feature overlap between MESA actigraphy and Basecamp CSI is substantial enough to make pretraining useful rather than decorative. MESA's activity_count corresponds to movement_power extracted from the CSI high-pass filter. MESA's zero_crossing_rate corresponds to the breathing regularity proxy derived from cross-subcarrier variance. Epoch-level context features (position within night, time since sleep onset, rolling movement statistics) are computable identically from both datasets.

The 30-second epoch size in MESA matches the 30-second window size used throughout this pipeline. This means features from MESA epochs and Basecamp windows are directly comparable without resampling or interpolation.

Published work using similar MESA-to-contactless transfer approaches reports a 5 to 8 percentage point improvement in three-class accuracy compared to training on heuristic labels alone. This is the only credible path to EEG-validated ground truth without attaching electrodes to the subject.

The MESA option was chosen over commercial wearables because PSG-validated labels are a qualitatively different signal from wearable estimates, and because the DAUA path is well-documented and approved specifically for academic research projects of this type.

## Consequences
The transfer learning notebook trains a Random Forest on MESA features and saves the pretrained weights to data/mesa_pretrained.pkl. After 30 or more personal nights have been collected, fine-tuning loads the pretrained weights and continues training on personal data. The fine-tuned model replaces the heuristic-only personalisation layer for sessions after that threshold.

Per DAUA section 8, raw MESA data files must not be committed to this repository and must be deleted within three years of project completion. Pretrained model weights derived from MESA data may be committed once generated.

Any publication or report using results from MESA-pretrained models must include the following acknowledgement: "NSRR R24 HL114473: NHLBI National Sleep Research Resource."

The notebook at analysis/mesa_transfer.ipynb runs end-to-end with synthetic stand-in data when the real MESA files are not present, so the pipeline can be reviewed and tested before data access is granted.

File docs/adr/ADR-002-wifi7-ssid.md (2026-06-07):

# ADR-002: Dedicated 2.4GHz SSID for WiFi 7 router

## Context
The home router is an ASUS RT-BE series (WiFi 7 / 802.11be). The ESP32-S3 firmware stack expects standard 802.11n behaviour on 2.4GHz. WiFi 7 introduces BSS colouring, MU-MIMO enhancements, and channel management features that interfere with CSI capture.

## Options considered
- Connect ESP32s directly to main WiFi network
- Create dedicated 2.4GHz SSID with legacy settings
- Use a separate TP-Link travel router (~80 RMB) dedicated to ESP32s

## Decision
Dedicated 2.4GHz SSID (RuView-24) with legacy mode settings on the ASUS router.

## Reasoning
The dedicated SSID approach is free, requires no additional hardware, and keeps the ESP32s on the same physical router as the Pi which connects via ethernet. Legacy mode settings (N only, 20MHz channel width, no MU-MIMO, no beamforming, no BSS colouring) replicate the 802.11n environment the ESP32 firmware expects.

## Router configuration

Apply these additional settings to the RuView-24 SSID on the ASUS router to ensure reliable CSI capture:

- Disable airtime fairness (AirTime Fairness / ATF)
- Disable Smart Connect (band steering)
- Disable band steering

## Consequences
WiFi 7 and ESP32-S3 CSI capture is untested in the RuView community. If CSI data is still corrupted after applying these settings, the fallback is a dedicated travel router (~80 RMB). This is an acceptable risk given the low cost of the fallback.

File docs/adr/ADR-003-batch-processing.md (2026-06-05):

# ADR-003: Batch processing vs real-time overnight inference

## Context
The system needs to process sensor data and produce a recovery score. The question is whether to run ML inference continuously overnight or log raw data and process everything in the morning.

## Options considered
- Continuous real-time inference overnight
- Hybrid: lightweight logging overnight, full batch processing in the morning
- Full batch only

## Decision
Batch processing. Three lightweight daemons log raw data overnight. All ML inference runs as a single batch job triggered by wake detection.

## Reasoning
I am asleep during data collection and cannot act on real-time output. Running ML inference overnight burns CPU continuously, generates heat which biases environmental sensors, and creates failure modes where a crashed process loses data mid-night. Batch processing is independently restartable, easier to debug, and produces results at the only moment they are useful which is after waking up.

## Consequences
No live feedback during the night. The only real-time output is bed presence detection via radar, which is a simple threshold operation rather than ML inference. Recovery score arrives approximately 5 to 8 minutes after waking.

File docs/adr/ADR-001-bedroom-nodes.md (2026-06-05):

# ADR-001: 2 bedroom nodes vs 1

## Context
The bedroom sensing zone requires WiFi CSI nodes to detect breathing rate, heart rate proxy, and sleep stages overnight. The question is whether one node is sufficient or whether two nodes provide meaningful improvement.

## Options considered
- 1 node on bedside table
- 2 nodes on opposite sides of bed

## Decision
2 nodes, one on bedside table (left), one on ledge (right), both at mattress height.

## Reasoning
When sleeping on one side, the body partially blocks the node on that side. A second node on the opposite side ensures at least one node always has a clean signal path to the chest. This is particularly important for breathing detection accuracy during REM sleep when movement is higher. The bed is 1.0-1.2m wide, putting both nodes at 0.5-0.6m from the chest, which is within the optimal sensing range.

## Consequences
Requires routing a 3-5m USB-C cable along the skirting board from the left-side wall sockets to the right node. Small added complexity unfortunately but increases reliability significantly.

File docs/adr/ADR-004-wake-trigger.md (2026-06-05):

# ADR-004: Bed exit trigger vs fixed time batch job

## Context
The morning batch job needs a trigger. The options are a fixed time (e.g. 7am) or a dynamic trigger based on detected wake time.

## Options considered
- Fixed 7am cron job
- Bed exit detected by radar triggers batch

## Decision
Radar-based bed exit trigger. Batch fires when radar detects bed exit after a minimum 4-hour sleep duration.

## Reasoning
A fixed time does not account for variable wake times. If I sleep until 9am, a 7am batch job runs on incomplete data. If I wake at 6am, I have to wait an hour for the report. The radar already runs overnight for presence detection, so bed exit is a zero-cost signal. The 4-hour minimum prevents bathroom trips at 3am from triggering the batch.

## Consequences
Requires the presence watcher daemon to remain running overnight. Adds a duration check before firing the trigger. Edge case: if the radar misses a bed exit, the batch does not run automatically and must be triggered manually.

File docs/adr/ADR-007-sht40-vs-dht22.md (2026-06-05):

# ADR-007: SHT40 vs DHT22 for temperature and humidity

## Context
The system needs a temperature and humidity sensor for environmental monitoring. Two common options are the DHT22 and the SHT40.

## Options considered
- DHT22: common, cheap, single-wire protocol
- SHT40: newer Sensirion sensor, I2C, higher accuracy

## Decision
SHT40.

## Reasoning
The SHT40 uses I2C, which is already used by BH1750, SCD40, and SGP40, all four environmental sensors share a single I2C bus, simplifying wiring significantly. The DHT22 uses a proprietary single-wire protocol requiring its own GPIO pin and a more complex software driver. The SHT40 also has better accuracy (+-0.2C vs +-0.5C) and faster response time, relevant for detecting subtle overnight temperature changes.

## Consequences
Marginal cost increase over DHT22. No other downsides.

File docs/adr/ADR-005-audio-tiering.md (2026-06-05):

# ADR-005: Audio storage tiering strategy

## Context
Logging raw audio overnight at 16kHz mono produces approximately 115MB per hour uncompressed, or roughly 700MB for a full night. A 32GB card fills in under 50 nights. Storage needs to be managed without risking loss of meaningful data.

## Options considered
- Store all audio compressed
- Real-time ML classifier to keep only interesting chunks
- Energy threshold tiering with bandpass snore detection

## Decision
Three-tier energy threshold system. Silence: timestamp only. Ambient: compressed low quality. Snore band (60-500Hz bandpass above threshold): compressed high quality with tag.

## Reasoning
A real-time ML classifier adds CPU load and risks false negatives where interesting audio is permanently discarded. Pure compression without filtering still produces ~150MB per night. The energy threshold approach requires only signal processing (no ML), runs cheaply overnight, reduces storage by approximately 70%, and preserves all audio above the silence threshold so no meaningful data is lost.

## Consequences
The silence threshold must be calibrated to the specific bedroom environment. If set too high, quiet breathing chunks are discarded. Threshold calibration is a one-time setup step on the first night.

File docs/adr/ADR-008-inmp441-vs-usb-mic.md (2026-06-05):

# ADR-008: INMP441 I2S microphone vs USB microphone

## Context
The system requires a microphone for snoring detection, breathing sounds, and apnea audio signatures. Two practical options are a USB condenser microphone and the INMP441 I2S digital microphone.

## Options considered
- USB condenser microphone (~30 RMB)
- INMP441 I2S digital microphone (~15 RMB)

## Decision
INMP441 I2S microphone.

## Reasoning
The INMP441 connects directly to the Pi via I2S (a dedicated digital audio interface), producing a clean digital signal without USB audio driver complexity. USB audio on Linux can introduce latency, requires driver configuration, and occupies a USB port needed for other peripherals. The INMP441 is also cheaper, smaller, and mounts directly on the enclosure PCB or breadboard. The I2S interface is well supported on Raspberry Pi via the built-in hardware audio clock.

## Consequences
Requires configuring the Pi's I2S interface in /boot/config.txt. Slightly more involved initial setup than plugging in a USB mic, but more reliable long-term.

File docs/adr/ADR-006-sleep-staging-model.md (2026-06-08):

# ADR-006: Sleep staging model architecture

## Context
The sleep stage classifier needs to infer sleep stages from fused CSI, radar, and audio features. The standard clinical model uses five classes: Wake, N1, N2, N3, and REM. The question is whether five-class staging is achievable with contactless WiFi CSI sensing, and which model architecture to use.

## Research findings
The best published contactless sleep staging results use radar-based transfer learning. An LSTM pretrained on movement, HRV, and respiratory features from the MESA Sleep dataset (1,100+ participants) then fine-tuned on 44 polysomnography recordings achieved a Matthews Correlation Coefficient of 0.47 for five-class staging. The fundamental limitation of contactless staging is that N1 and N2 are nearly indistinguishable without EEG, because the differences in respiration, heartbeat, and body movement between those two stages are not apparent from radio or acoustic signals alone.

There is no pretrained WiFi CSI sleep staging model available on Hugging Face or elsewhere that can be downloaded and used directly. The RuView model on Hugging Face is a CSI embedding encoder trained on a single overnight recording, not a sleep stage classifier, and its published accuracy numbers are not meaningful for generalisation.

## Options considered
- Five-class staging (Wake, N1, N2, N3, REM) with Random Forest
- Three-class staging (Wake, Deep, Light/REM) with Random Forest, upgraded to LSTM
- Transfer learning from MESA Sleep dataset actigraphy features, fine-tuned on personal data

## Decision
Three-class staging initially, with transfer learning from MESA as a planned Phase 3 upgrade.

Three classes:
- Wake: detected by radar movement spikes and CSI motion power above threshold
- Deep sleep: sustained low movement, slow regular breathing around 12 BPM, long uninterrupted windows
- Light and REM combined: everything else, with REM indicated by irregular breathing pattern with low movement

## Reasoning
Five-class staging is not achievable at meaningful accuracy with WiFi CSI alone. N1 and N2 require EEG to distinguish reliably. Attempting five-class staging with this hardware produces noisy, untrustworthy labels that undermine the recovery score. Three-class staging plays to the genuine strengths of the sensor stack: wake detection from radar is reliable, deep sleep has a distinctive radio and acoustic signature, and the light and REM distinction matters less for recovery scoring than deep sleep duration does.

The MESA transfer learning approach is the most technically interesting upgrade path. MESA is a publicly available dataset of 2,000+ participants with actigraphy-derived movement and respiratory features, which overlap significantly with what CSI and radar can measure. Pretraining on MESA features then fine-tuning on personal labelled nights is the approach used in the best academic contactless staging papers and has not been published as an open-source pipeline. This makes it a genuinely novel contribution for Phase 3 once 25+ nights of personal data are available.

## Realistic accuracy expectations

| Stage | Expected accuracy |
|---|---|
| Wake detection | ~88% |
| Deep sleep (N3) | ~75% |
| Light and REM combined | ~65% |
| Overall three-class | ~72-78% |

## Consequences
The recovery score uses deep sleep duration and proportion as its primary architecture metric, which three-class staging supports well. REM proportion is estimated from irregular breathing windows within the light and REM class rather than classified directly. This is an honest limitation documented in the README. The MESA transfer learning upgrade is tracked as a Phase 3 goal after 25+ nights of data are collected.

## Phase 3 upgrade

Access to the MESA Sleep dataset was approved under a Data Use Agreement (DAUA) with Brigham and Women's Hospital through the National Sleep Research Resource (NSRR). MESA contains 2,056 participants with simultaneous actigraphy and polysomnography annotations at 30-second epochs, which matches the window size used in this pipeline exactly.

The feature overlap between MESA actigraphy and Basecamp CSI is substantial. MESA's activity_count column maps to movement_power derived from the CSI high-pass component. The zero_crossing_rate column from MESA actigraphy maps to the breathing regularity proxy computed from cross-subcarrier variance. Epoch-level features such as epoch_position, time_since_sleep_onset, and rolling movement statistics are computable from both datasets without modification.

Pretraining a Random Forest on MESA features then fine-tuning on 30 or more personal labelled nights is the approach used in the best-performing published contactless staging work. Published results suggest this improves three-class accuracy by 5 to 8 percentage points compared to training on personal heuristic labels alone. This is the only credible path to EEG-validated ground truth in a single-subject system without attaching electrodes.

Per DAUA section 8, raw MESA data files must not be committed to the repository and must be deleted within three years of project completion. Pretrained model weights derived from MESA data may be committed. The notebook implementing this pipeline is at analysis/mesa_transfer.ipynb.

Required acknowledgement for any work using MESA data: "NSRR R24 HL114473: NHLBI National Sleep Research Resource."

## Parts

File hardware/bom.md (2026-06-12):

# Bill of materials

All components purchased from Taobao. Prices are approximate and may vary by seller.

| Component | Spec | Qty | Cost (RMB) |
|---|---|-----|---|
| ESP32-S3-DevKitC-1 | N16R8 -- 16MB flash, 8MB PSRAM | 2 | ~50 |
| Raspberry Pi 4 Model B | 4GB RAM | 1 | ~1000 |
| SanDisk MicroSD | 32GB Class 10 | 1 | ~25 |
| Pi power supply | Official 5V/3A USB-C | 1 | ~30 |
| INMP441 | I2S digital microphone | 1 | ~10 |
| HLK-LD2410C | 24GHz mmWave radar | 1 | ~25 |
| SHT40 | Temperature and humidity, I2C | 1 | ~15 |
| BH1750 | Light sensor, I2C, countersink mount | 1 | ~8 |
| SCD40 | CO2 sensor -- verify genuineness before use (see notes) | 1 | ~30 |
| SGP40 | VOC sensor, I2C | 1 | ~25 |
| 2.8 inch IPS SPI touchscreen | ILI9341 or ST7789 driver | 1 | ~30 |
| DS3231 RTC module | I2C real-time clock with CR2032 battery | 1 | ~10 |
| RGB LED + resistors | Recovery glow indicator (O3 lid hole) | 1 | ~2 |
| Ethernet cable 5m | Pi to router / switch | 1 | ~10 |
| 830-point breadboard | For prototype assembly | 1 | ~8 |
| Jumper wires | M-F, F-F, M-M sets | 1 set | ~10 |
| USB-A-to-C cable 25cm | Node 1 internal (Pi USB-A to Node 1) | 1 | ~5 |
| USB-A-to-C cable 5m 20AWG | Node 2 long run -- 20AWG wire gauge is a hard requirement; verify the listing specifies wire gauge, not just length | 1 | ~20 |
| Right-angle USB-C adapter | Pi power, exits through left wall slot | 1 | ~8 |
| M3 x 45mm pan-head black | Travel screws through rear posts -- install only before transport | 2 | ~5 |
| O6 x 3mm N35 disc magnets | Lid magnets -- buy 20-pack for spares; 12 used (6 pairs) | 20 | ~8 |
| O12mm adhesive rubber feet | Placed at four corners inboard | 4 | ~3 |
| VHB tape or foam tape | Screen module anti-rattle and sensor mounting | 1 sheet | ~5 |
| O8mm cable grommet | Pre-installed in chimney right wall | 1 | ~3 |
| M2.5 standoffs and screws | Pi mounting inside enclosure | 1 set | ~8 |
| Pi 4 heatsink | Compute zone ventilates through rear IO opening | 1 | ~8 |
| 3D printed enclosure v4 | Matte black PLA, 96 x 136 x 49mm assembled | 1 | ~40 |

## Total

Approximately 1410 RMB depending on sellers and shipping.

## Notes

The SCD40 is the only component where clones are a significant problem. Fake chips produce plausible-looking but inaccurate CO2 readings, which would corrupt the environmental layer of the recovery score. To verify genuineness, check the following before use.

The genuine Sensirion SCD40 has the Sensirion logo and the text SCD40 printed clearly on the chip itself. The chip is a small square package soldered onto the breakout board. If the chip markings are absent, smudged, or show a different manufacturer name, it is likely a clone. A second verification method is to run the sensor outdoors for twenty minutes and check whether the reading converges on approximately 400 to 420 ppm, which is the current atmospheric CO2 concentration. A genuine sensor will stabilise in this range. A clone will typically read too high, too low, or fail to stabilise at all.

If the sensor turns out to be a clone, a genuine replacement costs approximately 75 to 80 RMB from a reputable seller and is worth the price given how central the CO2 data is to the environmental scoring layer.

All four environmental sensors (SHT40, BH1750, SCD40, SGP40) and the DS3231 RTC share a single I2C bus, which simplifies wiring considerably. Buy all sensors as breakout boards with pre-soldered headers to avoid soldering during the prototype phase.

**Node 2 cable gauge:** The 5m USB-A-to-C cable for Node 2 must be 20AWG wire or thicker. Thin cables (28AWG is common for cheap listings) cause voltage drop during ESP32-S3 WiFi TX bursts, triggering brownout resets. Verify the listing specifies wire gauge, not just cable length.

The 3D printed enclosure can be ordered as a print service on Taobao by uploading the STL files from the hardware/enclosure folder. Request 0.2mm layer height and matte black PLA. v4 is slightly smaller than v3; expect approximately Y40.

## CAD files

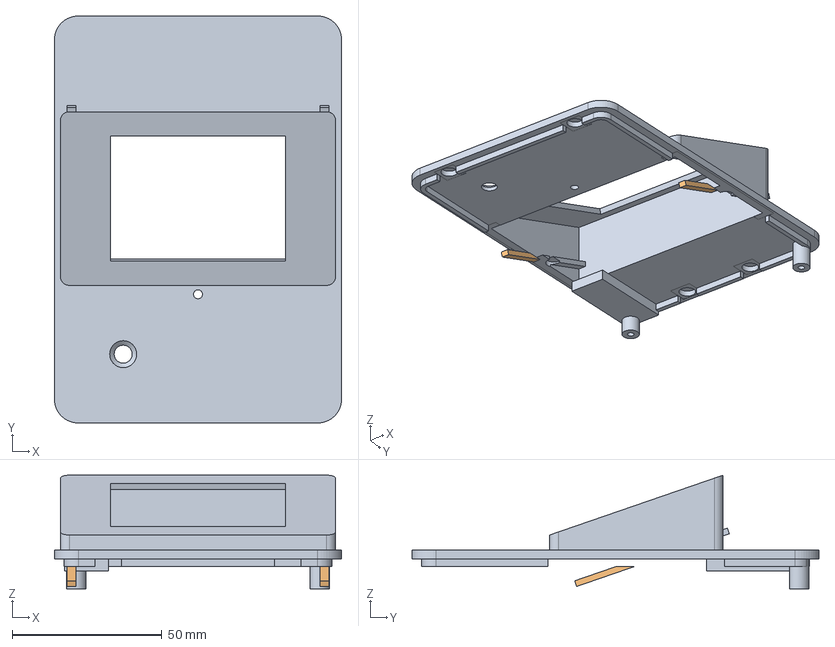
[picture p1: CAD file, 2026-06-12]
hardware/enclosure/basecamp_lid_v4.step
96.0 x 136.0 x 38.0 mm

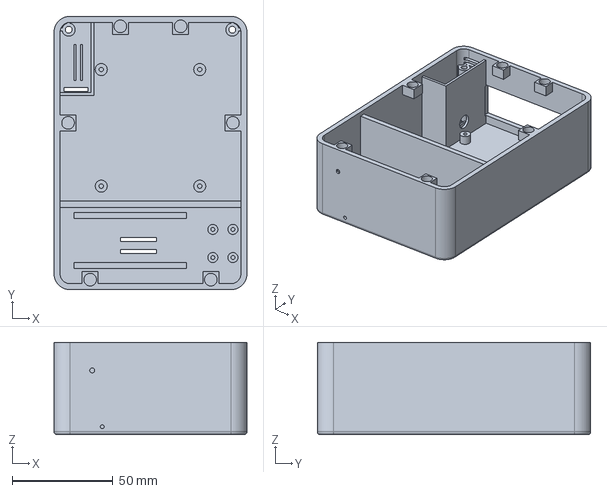
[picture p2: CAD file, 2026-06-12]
hardware/enclosure/basecamp_body_v4.step
96.0 x 136.0 x 46.0 mm

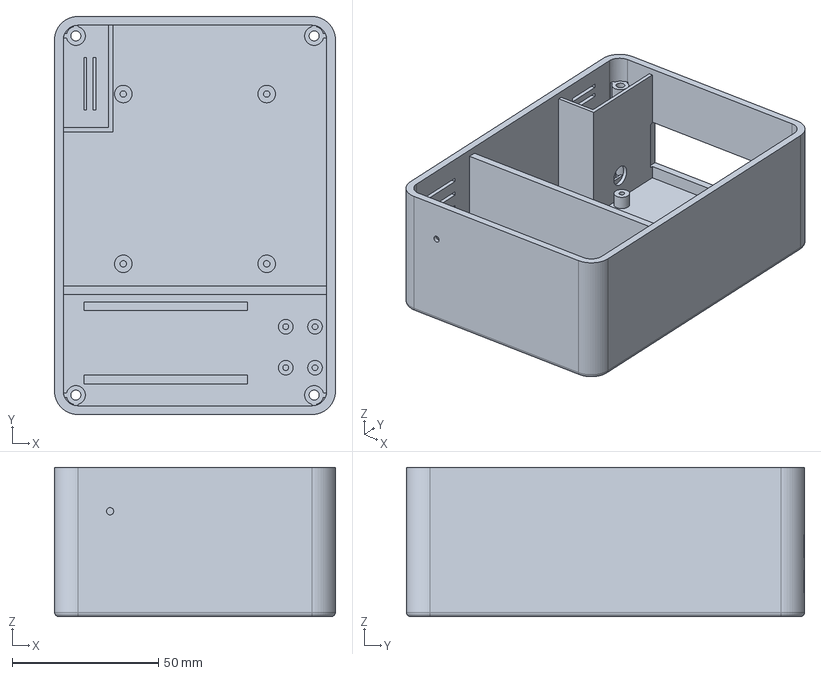
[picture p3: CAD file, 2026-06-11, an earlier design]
hardware/enclosure/archive/v3/basecamp_body_v3.step
96.0 x 136.0 x 51.0 mm

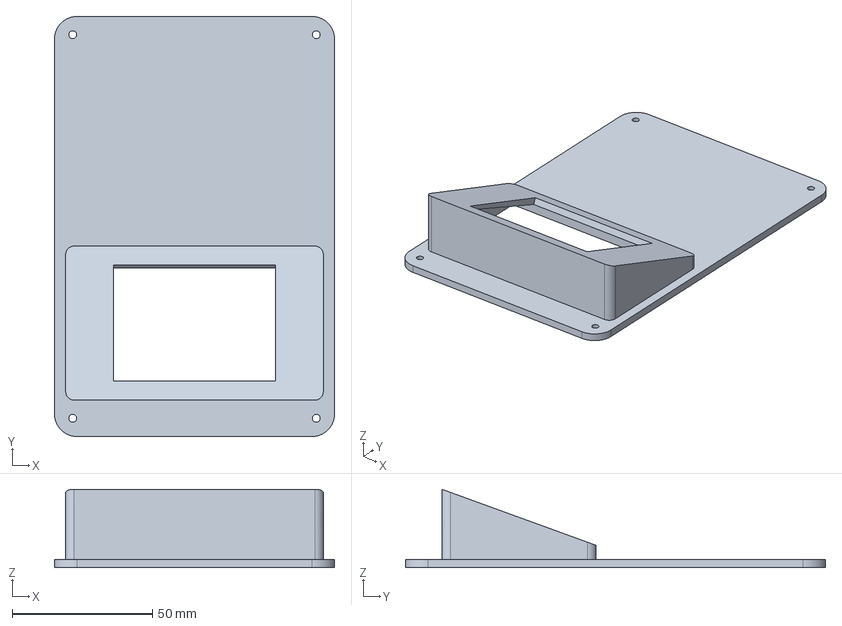
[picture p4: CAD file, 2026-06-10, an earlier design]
hardware/enclosure/basecamp_lid_v2.step
100.0 x 150.0 x 28.0 mm

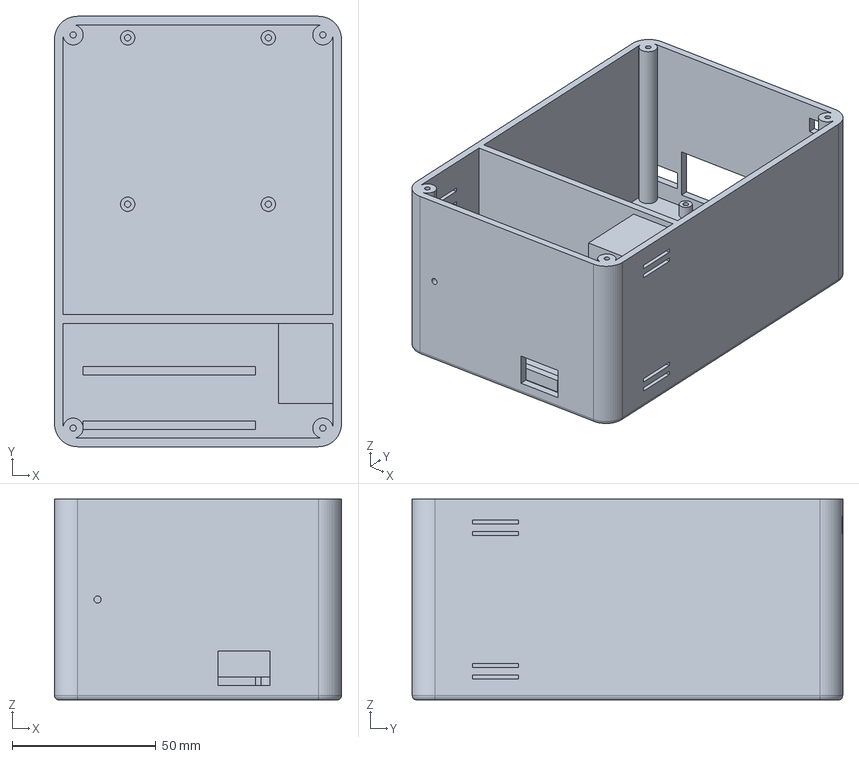
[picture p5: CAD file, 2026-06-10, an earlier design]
hardware/enclosure/basecamp_body_v2.step
100.0 x 150.0 x 70.0 mm

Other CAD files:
hardware/enclosure/archive/v3/basecamp_lid_v3.step
hardware/enclosure/basecamp_lid_v3.step
hardware/enclosure/archive/v3/basecamp_body_v3.stl
hardware/enclosure/archive/v3/basecamp_lid_v3.stl
hardware/enclosure/basecamp_body_v3.stl
hardware/enclosure/basecamp_body_v4.stl
hardware/enclosure/basecamp_lid_v3.stl
hardware/enclosure/basecamp_lid_v4.stl

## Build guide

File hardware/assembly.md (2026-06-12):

# Hardware Assembly and Bring-Up

Step-by-step guide for assembling and verifying Basecamp from components to first overnight run.

**Time required:** Allow a full day for first assembly. Most steps have a verification command -- do not skip them.

---

## 0. Pre-Assembly Checklist

### Components
Verify all BOM items are present before starting.

- [ ] Raspberry Pi 4 Model B 4GB
- [ ] SanDisk 32GB MicroSD card
- [ ] Official Pi USB-C power supply (5V/3A)
- [ ] Right-angle USB-C adapter
- [ ] ESP32-S3-DevKitC-1 N16R8 x 2
- [ ] INMP441 I2S microphone
- [ ] HLK-LD2410C mmWave radar
- [ ] SHT40 temperature/humidity sensor
- [ ] BH1750 light sensor
- [ ] SCD40 CO2 sensor -- verify genuine Sensirion logo printed on chip before proceeding
- [ ] SGP40 VOC sensor
- [ ] DS3231 RTC module with CR2032 battery installed
- [ ] RGB LED + resistors
- [ ] 2.8" IPS SPI touchscreen (ILI9341 or ST7789 driver)
- [ ] USB-A-to-C cable 25cm (Node 1 internal)
- [ ] USB-A-to-C cable 5m 20AWG (Node 2 long run) -- verify listing states wire gauge
- [ ] Ethernet cable 5m
- [ ] 12x O6x3 N35 disc magnets (plus spares from 20-pack)
- [ ] 2x M3x45 pan-head screws (travel screws)
- [ ] O12mm adhesive rubber feet x4
- [ ] VHB tape / foam tape
- [ ] Breadboard + jumper wires (M-F, F-F, M-M)
- [ ] M2.5 standoffs and screws
- [ ] 3D printed enclosure v4 (if ordered -- see note below)

> **Enclosure note:** Print time plus shipping is 5-7 days. If the enclosure has not arrived, proceed with the breadboard. All verification steps work without the enclosure.

### Tools
- MicroSD card reader
- Computer with Raspberry Pi Imager installed
- A second device (phone or laptop) to access the Pi web interface
- Multimeter (optional but useful for continuity checks)

---

## 1. Flash the MicroSD Card

On your computer:

1. Download and open [Raspberry Pi Imager](https://www.raspberrypi.com/software/)
2. Choose OS -> **Raspberry Pi OS Lite (64-bit)** -- no desktop needed
3. Choose storage -> your SanDisk 32GB card
4. Click the gear icon and configure:
   - Set hostname: `basecamp`
   - Enable SSH with password authentication
   - Set username: `pi`, password: your choice
5. Write to card

Insert the card into the Pi. Connect ethernet to your router or switch. Connect power via the right-angle USB-C adapter through the left wall slot.

Wait 60 seconds for first boot, then find the Pi's IP address from your router's admin page, or:

```bash
# From another machine on the same network
ping basecamp.local
```

SSH in:

```bash
ssh pi@basecamp.local
```

**Magnet assembly (if enclosure has arrived):** Before mounting any electronics, install and glue the lid magnets.

1. Dry-stack all 12 magnets into their body and lid pockets without glue.
2. Close the lid and verify it seats and releases cleanly at all six points.
3. Open the lid carefully. Mark the outward-facing face of each magnet with a permanent marker before removing them.
4. Glue body-side magnets mark-up (recessed 0.8mm into wall-boss pocket), lid-side magnets mark-down (proud 0.8mm from lid underside). Use CA glue or epoxy. Hold 30 seconds per magnet.
5. Allow full cure before closing the lid again.

---

## 2. Run the Setup Script

```bash
# Clone the repo
git clone https://github.com/Windows1985/Basecamp.git /home/pi/basecamp
cd /home/pi/basecamp

# Run setup (takes 10-15 minutes)
sudo bash pi_setup.sh
```

The script configures wlan0 as an isolated AP for the ESP32 nodes, sets eth0 as a DHCP client for internet and NTP, enables the DS3231 RTC overlay, installs all Python dependencies, configures UART for the radar, enables I2C/SPI, and installs systemd services.

Pi power enters through the left wall slot via the right-angle USB-C adapter -- no internal routing needed.

Reboot after the script completes:

```bash
sudo reboot
```

---

## 3. Configure ntfy

The morning report and crash notifications are sent via ntfy. Set up before the first overnight run.

1. Install the [ntfy app](https://ntfy.sh) on your phone
2. Subscribe to a topic name of your choice (e.g., `basecamp-ethan-2024`) -- keep it unguessable
3. Edit the config on the Pi:

```bash
nano /home/pi/basecamp/server/config.py
```

Set `NTFY_TOPIC` to your chosen topic name. Save and close.

Test the notification:

```bash
curl -d "Basecamp test notification" ntfy.sh/YOUR_TOPIC_NAME
```

You should receive a notification on your phone within a few seconds.

---

## 4. Node power verification

Both ESP32 nodes draw power directly from the Pi's rear USB-A ports.

- Node 1: 25cm USB-A-to-C cable from rear Pi USB-A port, routed internally.
- Node 2: 5m 20AWG USB-A-to-C cable from the other rear Pi USB-A port, exiting through the IO cutout.

Before powering the nodes, verify the Node 2 cable gauge:

```bash
# Measure voltage at the Node 2 connector end while the node is running
# Should read >= 4.75V under WiFi TX load; if below 4.6V the cable is too thin
```

If voltage sags below 4.6V under load, the cable is not 20AWG -- replace it before proceeding.

---

## 5. Verify I2C Sensors and RTC

Wire all I2C devices to the Pi before this step. All share GPIO 2 (SDA) and GPIO 3 (SCL). See `hardware/wiring.md` for full pin reference.

| Device | I2C Address |
|---|---|
| BH1750 | 0x23 |
| SHT40 | 0x44 |
| SGP40 | 0x59 |
| SCD40 | 0x62 |
| DS3231 RTC | 0x68 |

```bash
sudo i2cdetect -y 1
```

Expected output shows all five addresses populated. Example:

```
     0  1  2  3  4  5  6  7  8  9  a  b  c  d  e  f
00:          -- -- -- -- -- -- -- -- -- -- -- -- --
10: -- -- -- -- -- -- -- -- -- -- -- -- -- -- -- --
20: -- -- -- 23 -- -- -- -- -- -- -- -- -- -- -- --
30: -- -- -- -- -- -- -- -- -- -- -- -- -- -- -- --
40: -- -- -- -- 44 -- -- -- -- -- -- -- -- -- -- --
50: -- -- -- -- -- -- -- -- -- 59 -- -- -- -- -- --
60: -- -- 62 -- -- -- -- -- 68 -- -- -- -- -- -- --
```

If an address is missing, check the wiring for that device. SDA/SCL reversed and insufficient 3.3V power are the most common causes.

**SGP40 burn-in:** SGP40 requires 24 hours of continuous operation before VOC readings stabilise. Leave the Pi running after this step and do not trust VOC output until the following day.

---

## 6. Verify RTC timekeeping

After the DS3231 is detected on the I2C bus, verify the RTC is providing time:

```bash
# Write current time to the RTC
sudo hwclock -w

# Check timedatectl shows RTC time
timedatectl

# Simulate offline power cycle: disconnect ethernet, reboot, check time is correct
sudo reboot
```

After rebooting without ethernet, run:

```bash
timedatectl
# "RTC time" should match wall clock within a few seconds
# "System clock synchronized: no" is expected when offline -- that is correct
```

If the time is wrong by hours or days after an offline reboot, fake-hwclock may still be active. Disable it:

```bash
sudo systemctl disable fake-hwclock
sudo systemctl stop fake-hwclock
sudo update-rc.d fake-hwclock disable
```

---

## 7. Calibrate the SCD40

Take the Pi outdoors (or near an open window) for this step. Outdoor CO2 is approximately 420ppm -- this is the calibration reference.

```bash
cd /home/pi/basecamp
python3 server/calibrate_scd40.py
```

The script runs for approximately 3 minutes and prints readings. Expected output: 400-450ppm.

If readings are consistently outside 380-480ppm, the chip is likely a clone. Replace it before proceeding.

---

## 8. Verify the Radar

The HLK-LD2410C requires **5V power** (not 3.3V) and the Pi's hardware UART. Verify `dtoverlay=disable-bt` is present in `/boot/config.txt` (pi_setup.sh adds this automatically).

Wire the radar TX->GPIO 15 (Pi RXD), RX->GPIO 14 (Pi TXD), VCC->5V pin, GND->GND.

```bash
python3 -c "
import serial, time
s = serial.Serial('/dev/ttyAMA0', 256000, timeout=2)
time.sleep(0.5)
data = s.read(100)
print(f'Read {len(data)} bytes: {data.hex()}')
s.close()
"
```

Expected: reads 100 bytes of radar output. If `len(data)` is 0, check TX/RX are not swapped.

---

## 9. Verify the Microphone

Wire INMP441 to GPIO 18 (BCK), 19 (LRCK), 20 (DIN). See `hardware/wiring.md` for full pinout including L/R select.

```bash
# Record 3 seconds of audio
arecord -D plughw:1 -c1 -r 16000 -f S32_LE -d 3 /tmp/test.wav
# Play it back
aplay /tmp/test.wav
```

---

## 10. Verify the Touchscreen

Wire the ILI9341 touchscreen to the SPI pins. See `hardware/wiring.md` for full pinout.

```bash
cd /home/pi/basecamp
python3 server/screen.py --test
```

Expected: the screen displays the IDLE layout (time, no score).

---

## 11. Flash and Verify ESP32 Node 1

Follow the instructions in `firmware/README.md` to flash the ESP32-CSI-Tool firmware.

Key configuration before flashing:
- Target SSID: `Basecamp-Node` (the Pi's own hotspot)
- UDP target IP: `192.168.4.1` (the Pi's AP address)
- UDP target port: `5500` (default in `server/config.py`)

On the Pi, verify the CSI stream is arriving:

```bash
cd /home/pi/basecamp
timeout 10 python3 -c "
import socket
s = socket.socket(socket.AF_INET, socket.SOCK_DGRAM)
s.bind(('0.0.0.0', 5500))
s.settimeout(2)
count = 0
while True:
    try:
        data, addr = s.recvfrom(4096)
        count += 1
        print(f'Packet {count}: {len(data)} bytes from {addr}')
        if count >= 5:
            break
    except socket.timeout:
        print('Timeout -- no packets received')
        break
"
```

Expected: 5 packets received within 10 seconds. If no packets arrive, verify the ESP32 is connected to `Basecamp-Node` (check `hostapd` logs for association events).

---

## 12. First Overnight Run (Single Node)

Start all services:

```bash
sudo systemctl start basecamp-logger basecamp-presence basecamp-audio basecamp-csi basecamp-screen
```

Verify all are running:

```bash
sudo systemctl status basecamp-*
```

**Final assembly (if enclosure has arrived):**

1. Close lid by lowering it onto the body. Listen for the magnetic click at all six points -- front two, rear two, mid-side two.
2. Travel screws are NOT installed unless transporting.
3. Rubber feet go at the four corners inboard; counterbores are at the two rear posts only.

---

## 13. Flash and Add ESP32 Node 2

Once the first overnight run completes without errors, flash Node 2 with the same firmware configuration as Node 1.

Place Node 2 on the right ledge, antenna end facing the bed, at mattress height. Route the 5m 20AWG USB-A-to-C cable to the rear Pi USB-A port through the IO cutout.

Verify both nodes are streaming simultaneously:

```bash
cd /home/pi/basecamp
timeout 15 python3 -c "
import socket
s = socket.socket(socket.AF_INET, socket.SOCK_DGRAM)
s.bind(('0.0.0.0', 5500))
s.settimeout(2)
from collections import defaultdict
sources = defaultdict(int)
import time; end = time.time() + 10
while time.time() < end:
    try:
        data, addr = s.recvfrom(4096)
        sources[addr[0]] += 1
    except socket.timeout:
        pass
for ip, count in sources.items():
    print(f'{ip}: {count} packets')
"
```

Expected: two source IPs, each with a similar packet count.

---

## 14. Submit First Morning Log

After the second overnight run completes, open the morning log via the touchscreen or the web interface:

```
http://basecamp.local:5000
```

Submit Recovery, Energy, Clarity, and Mood scores (1-10 each).

---

## Known First-Boot Issues

| Symptom | Likely cause | Fix |
|---|---|-----|
| `i2cdetect` shows no addresses | I2C not enabled | Verify `dtparam=i2c_arm=on` in `/boot/config.txt`; reboot |
| DS3231 (0x68) not detected | RTC not wired or overlay missing | Add `dtoverlay=i2c-rtc,ds3231` to `/boot/config.txt`; reboot |
| Radar reads 0 bytes | Bluetooth not disabled, wrong UART | Verify `dtoverlay=disable-bt` in `/boot/config.txt`; check TX/RX not swapped |
| SCD40 reads outside 380-480ppm outdoors | Clone chip | Replace sensor |
| CSI no packets | ESP32 not on Basecamp-Node, wrong UDP IP | Check `hostapd` association log; verify UDP target is 192.168.4.1 |
| Screen stays blank | SPI not enabled, DC/RESET swapped | `ls /dev/spidev*`; check GPIO 24/25 wiring |
| SGP40 VOC reads erratic | Normal for first 24 hours | Wait for burn-in to complete |
| ntfy notification not received | Topic name mismatch | Verify `NTFY_TOPIC` in `server/config.py` matches phone subscription |
| Node 2 brownout resets during WiFi TX | 5m cable is too thin | Replace with 20AWG cable; verify listing states wire gauge |
| Lid doesn't seat flush | Magnet glued proud on body side | Press body-side magnet deeper into pocket with a flat tool; re-glue if loose |
| Time wrong after offline power cycle | RTC battery flat or fake-hwclock still active | Replace CR2032; disable fake-hwclock via systemctl |

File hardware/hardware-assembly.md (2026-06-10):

# Enclosure Assembly Guide

Step-by-step guide for assembling all hardware into the Basecamp enclosure.
Follow after `hardware/assembly.md` (Pi OS setup and daemon verification) is complete.

**Prerequisites:**
- All five daemons verified working in breadboard configuration
- All sensors passing their verification tests from `hardware/assembly.md`
- Enclosure printed and in hand (body + lid)
- All BOM components present

**Tools needed:**
- JIS/Phillips screwdriver (M2.5)
- Flush cutters or scissors (cable management)
- Tweezers
- Multimeter (continuity check on cable crimps)
- Small file or sandpaper (if any print tolerances are tight)

**Time:** Allow 3–4 hours. Do not rush the wiring pass.

---

## 0. Print Inspection

Before starting, inspect the print for the following:

- [ ] Radar membrane (front face) is approximately 1mm thick — hold it to a light source and check for even translucency. If the membrane printed too thick (>1.5mm), sand from the inside with a fine file.
- [ ] Antenna window (front face, right side) is fully open — no layer bridging across the aperture
- [ ] USB service slot (left wall) is fully open and both USB-C port openings clear
- [ ] Screen pod cavity is accessible from below — ribbon slot (20×4mm) under pod is open
- [ ] All four corner post screw holes accessible
- [ ] SCD40 chimney cap is solid — no gaps or layer separation
- [ ] All vent slots fully open — run a toothpick through each

Sand any tight-tolerance features with 400-grit before proceeding. The ESP32 recess and screen pod are the most likely to need light cleanup.

---

## 1. Install Pi Standoffs

Insert four M2.5×5mm brass standoffs into the standoff bosses on the compute zone floor. These should press-fit; if loose, add a drop of super glue around the base.

Verify the standoff pattern matches the Pi 4 mounting holes: 58×49mm, 3.5mm from each edge. Place the Pi dry (no screws) and check all four holes align before proceeding.

---

## 2. Mount the Raspberry Pi

Lower the Pi into the compute zone with the USB/ethernet ports facing the rear wall of the enclosure. Align all four mounting holes over the standoffs.

Secure with four M2.5×4mm screws. Do not overtighten — brass standoffs strip easily. Finger-tight plus a quarter turn is sufficient.

**Verify:** USB-A ports and ethernet jack are aligned with the rear I/O cutout. If any port is obstructed, the Pi position may be off-centre — loosen, re-seat, re-tighten.

---

## 3. Mount the USB Hub

Place the powered USB hub in the rear of the compute zone, to the side of the Pi. The exact position depends on your hub's form factor. Route its power cable under itself toward the USB-C power entry slot on the rear wall.

If the hub has mounting holes, use M3 screws into the floor. Otherwise cable-tie it to the Pi standoff posts using two ties in a loop. It must not shift when USB cables are plugged or unplugged.

Connect the hub's upstream USB-A port to one of the Pi's USB-A ports now, before the space gets crowded.

---

## 4. Install the Integrated ESP32 (Node 1)

Node 1 sits in the sensor zone on the two rails parallel to the front face. The board lies flat, component-side up, with the antenna end (WROOM module side) toward the front face, aligned with the antenna window.

Lower the board onto the rails with the USB-C ports facing left, aligned with the USB service slot in the left wall. The board should sit flush on the rails with the WROOM module antenna centred behind the antenna window.

**Verify alignment:**
- Looking through the antenna window from the front, you should see the WROOM module's metal can directly behind it
- Looking at the left wall service slot, both USB-C port openings should be accessible from outside

Secure with two M2.5×6mm screws through the DevKit's mounting holes (if present) into the rail. If the board has no mounting holes, use a cable tie across the board through slots in the rails.

Connect a short USB-C cable (0.5m) from Node 1's USB port to the powered hub. Route under the baffle through the 5mm gap at the bottom.

---

## 5. Install I2C Sensors (Compute Zone)

The four I2C sensors (SHT40, BH1750, SCD40, SGP40) mount in the sensor zone on the opposite side of the baffle from the ESP32. All four share GPIO 2 (SDA) and GPIO 3 (SCL).

**SCD40 placement — critical:** Mount the SCD40 inside the chimney column (right wall side, isolated from the rest of the sensor zone). The chimney's low vents at Z=8mm and Z=12mm are the air intake; the high vents at Z=58mm and Z=62mm are exhaust. The sensor must be inside this column to measure room air, not Pi-heated air.

Mount the SCD40 on a small standoff (3mm) inside the chimney, with its measurement port facing up toward the cap. Use M2×4mm screws or double-sided thermal tape. Ensure the sensor body is not bridging the chimney wall — it must sit within the isolated column.

**BH1750 placement:** Mount facing up in the sensor zone, clear of the ESP32 board. It measures ambient light through the vent grille — position it below a vent slot.

**SHT40 and SGP40:** Mount on a small breakout board or breadboard section secured to the sensor zone floor. Keep both away from the SCD40 chimney (temperature gradient would affect SHT40) and away from the Pi (same reason).

Wire all four to the Pi GPIO header. The harness routes through the 5mm baffle gap. Leave slack — the lid needs to seat without tension on cables.

---

## 6. Install the Radar

The HLK-LD2410C mounts in the sensor zone with its sensing face toward the front wall. The radar works through the 1mm membrane — it does not need an open aperture.

Mount with double-sided tape or small brackets on the sensor zone floor, centred on the radar membrane (front face centre-right). The radar face should be flush against or within 3mm of the inner front wall.

Wire TX→GPIO 15, RX→GPIO 14, VCC→5V, GND→GND. Route the cable through the baffle gap to the Pi.

**Verify:** Run `python3 -c "import serial; s = serial.Serial('/dev/ttyAMA0', 256000, timeout=2); print(len(s.read(100)))"` — should return 100.

---

## 7. Install the Microphone

The INMP441 microphone mounts in the sensor zone with the port (small hole on the component side) aligned with the 2.5mm mic hole in the front face.

Use a small bracket or folded cardboard shim to position the mic at the exact height of the mic hole (Z=35mm). The port must be within 2mm of the inner face of the front wall. Secure with tape.

Wire BCK→GPIO 18, LRCK→GPIO 19, DIN→GPIO 20, L/R→GND. Route through baffle gap.

**Verify:** `arecord -D plughw:1 -c1 -r 16000 -f S32_LE -d 2 /tmp/test.wav && aplay /tmp/test.wav`

---

## 8. Screen Preparation

Before fitting the screen, attach the SPI ribbon cable (if not already attached) and test it on the bench:

```bash
python3 server/screen.py --demo
```

Confirm the IDLE layout displays correctly. If the screen is blank, fix it now — access is much harder after the lid is on.

Thread the ribbon cable through the ribbon slot (20×4mm slot under the screen pod) from above. Route it down through the sensor zone, through the baffle gap, and to the Pi GPIO header.

---

## 9. Seat the Lid

Before screwing the lid down:

1. Lay all cables flat — nothing should be pinched between the lid and body rim
2. Check the ribbon cable is not kinked at the baffle gap
3. Confirm the SCD40 chimney cap is not in contact with any cable

Lower the lid onto the body. The screen pod sits over the sensor zone. The corner posts should align with the lid screw holes — if the lid rocks, a corner post may have printed slightly tall; file it down.

Secure with four M2.5×8mm screws through the lid corners into the body posts. Snug, not tight.

Insert the screen module into the pod from the front face side. The PCB (86×50mm) slides into the pod cavity. The active display area should be visible through the screen window in the slanted face. Secure with two M2 screws through the PCB mounting holes into the pod, or with a thin bead of hot glue along the PCB edges.

---

## 10. External Connections

With the lid on:

**Rear face:**
- Ethernet: connect the 5m cable to the Pi ethernet port through the rear I/O cutout, route to the router or switch
- USB-C power: connect the Pi PSU through the rear USB-C slot
- Node 2 exit: route the 3–5m USB-C cable for the satellite node through the top-right exit slot, feed a grommet over it, seat the grommet in the groove

**Left wall service slot:**
- Leave accessible — this is used for Node 1 firmware provisioning

**Powered hub AC adapter:**
- Routes out the rear alongside the Pi PSU; use a cable clip or velcro to keep both tidy

---

## 11. Node 2 (Satellite)

Node 2 is external — it sits on the right-side ledge at mattress height. It is not enclosed.

Mount the bare ESP32-S3 DevKit on a small 3D-printed or cardboard bracket so it sits flat at mattress height with the antenna end facing the bed. The USB-C cable routes along the skirting board to the hub inside the enclosure.

No soldering or permanent mounting needed for Node 2 — it can be repositioned.

---

## 12. Final Checks

Power everything on. With the enclosure assembled:

```bash
# All five daemons healthy
sudo systemctl status basecamp-*

# Both CSI nodes streaming
timeout 10 python3 -c "
import socket, time
from collections import defaultdict
s = socket.socket(socket.AF_INET, socket.SOCK_DGRAM)
s.bind(('0.0.0.0', 5500))
s.settimeout(2)
src = defaultdict(int)
end = time.time() + 8
while time.time() < end:
    try:
        _, addr = s.recvfrom(4096)
        src[addr[0]] += 1
    except: pass
[print(f'{ip}: {n} packets') for ip, n in src.items()]
print(f'nodes active: {len(src)}')
"

# I2C sensors still responding
sudo i2cdetect -y 1

# Screen showing IDLE layout
# (verify visually)
```

Expected: 5 daemons active, 2 UDP source IPs, all 4 I2C addresses, screen showing time.

---

## 13. Cable Management

Before calling it done:

- Zip-tie the harness from the Pi GPIO header into a single bundle through the baffle gap
- Cable-tie the Node 1 USB cable under the baffle
- Ensure no cable is under tension — every cable should have at least 20mm of slack at its shortest point
- Check that the Pi's USB-A port retaining force doesn't move the hub when plugged/unplugged

---

## Troubleshooting

| Symptom | Likely cause | Fix |
|---|---|-----|
| Screen blank after lid seated | Ribbon cable kinked at baffle gap | Open lid, re-route ribbon with a gentle S-bend through the gap |
| SCD40 reads like indoor air even with window open | Sensor outside chimney column | Check sensor is seated inside the chimney, not beside it |
| Radar reads 0 bytes | Cable snagged on lid seating | Open lid, check TX/RX continuity with multimeter |
| Only 1 CSI node visible | Node 1 USB cable not routed through baffle gap | Check under baffle — hub may have lost the connection |
| I2C addresses missing after assembly | Cable tension pulled a Dupont pin | Check harness at GPIO header and at sensor breakout |
| Screen shows correct layout but touch unresponsive | IRQ pin (GPIO 17) cable caught | Re-seat GPIO 17 connection |

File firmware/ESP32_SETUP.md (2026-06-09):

# ESP32 Firmware Setup and Flash Guide

Step-by-step guide for building, configuring, and flashing both ESP32-S3 nodes.

**Time required:** 1–2 hours for first-time setup including toolchain installation. Second node is 15 minutes once the first is working.

---

## 0. Prerequisites

- ESP32-S3-DevKitC-1 N16R8 × 2
- USB-C cable connected to your Windows machine
- Pi's static IP address reserved in your router's DHCP settings before starting — you need this for the UDP target config
- `RuView-24` dedicated 2.4GHz legacy SSID active on the ASUS RT-BE router

---

## 1. Install ESP-IDF on Windows

Download and run the official Windows installer from:
**https://dl.espressif.com/dl/esp-idf/**

Select **ESP-IDF v5.4** (or v5.2 — both work; v5.4 has better S3 support). The installer sets up the full toolchain, Python environment, and adds `idf.py` to your path via the ESP-IDF Command Prompt shortcut.

After installation, always open the **ESP-IDF v5.x CMD** shortcut rather than a regular terminal — it sets the environment variables correctly.

**Alternative: Docker (no local toolchain needed)**

If the installer causes issues on your restricted school device, use Docker instead. Build runs entirely in a container:

```bash
# From active_sta/ directory (Git Bash or WSL)
MSYS_NO_PATHCONV=1 docker run --rm -v "$(pwd):/project" -w /project \
  espressif/idf:v5.4 bash -c \
  "rm -rf build sdkconfig && idf.py set-target esp32s3 && idf.py build"
```

Build output appears in `build/`. First build takes 3–5 minutes; incremental rebuilds ~30 seconds.

---

## 2. Clone ESP32-CSI-Tool

```bash
git clone https://github.com/StevenMHernandez/ESP32-CSI-Tool.git
cd ESP32-CSI-Tool/active_sta
```

All commands below run from `active_sta/`.

---

## 3. Set Target to ESP32-S3

```bash
idf.py set-target esp32s3
```

This must be run once before menuconfig or build. It generates the correct `sdkconfig` base for the S3.

---

## 4. Configure — Node 1

```bash
idf.py menuconfig
```

Navigate with arrow keys, Enter to select, Q to quit and save. Set the following:

### ESP32 CSI Tool Config
| Setting | Value |
|---|---|
| WiFi SSID | `RuView-24` |
| WiFi Password | your password |

> **Note:** SSID and password in menuconfig are compile-time fallbacks only — provision.py overrides them at runtime via NVS. You still need to set them here so the firmware has a fallback if NVS is blank.

### Serial flasher config
| Setting | Value |
|---|---|
| Default baud rate | `921600` |

### Component config → FreeRTOS
| Setting | Value |
|---|---|
| Tick rate (Hz) | `1000` |

> **Important:** The FreeRTOS tick rate affects CSI timing accuracy. Default is 100Hz — change it to 1000Hz or breathing rate estimation degrades.

Save and exit menuconfig (Q → Y).

---

## 5. Build — Node 1

```bash
idf.py build
```

First build: ~5 minutes, ~1400 compilation steps. You should see `Project build complete` with no errors.

---

## 6. Flash — Node 1

Put the ESP32-S3 into download mode:
1. Hold the **BOOT** button
2. Press and release **RESET**
3. Release **BOOT**

Find your COM port: open Device Manager → Ports (COM & LPT). It will appear as `USB Serial Device (COMx)` or `CP210x (COMx)`.

Use `flash.sh` from the repo root (run from Git Bash, WSL, or Linux/Mac terminal):

```bash
./firmware/flash.sh 1 COM7
```

Replace `COM7` with your actual port (e.g. `/dev/ttyUSB0` on Linux). The script validates that a build exists, prints the esptool command, and runs it.

Expected output ends with:
```
Hash of data verified.
Leaving...
Hard resetting via RTS pin...
Flash complete. Now provision Node 1: ...
```

> **Fallback — manual esptool command**
>
> If `flash.sh` is unavailable (e.g. on a restricted Windows device without Git Bash):
> ```bash
> python -m esptool --chip esp32s3 --port COM7 --baud 460800 \
>   --before default-reset --after hard-reset \
>   write-flash --flash-mode dio --flash-freq 80m --flash-size 16MB \
>   0x0     build/bootloader/bootloader.bin \
>   0x8000  build/partition_table/partition-table.bin \
>   0x10000 build/esp32-csi-node.bin
> ```
> Use `--flash-size 16MB` — the N16R8 has 16MB flash, not 4MB.

---

## 7. Verify Node 1

Open the serial monitor at 921600 baud:

```bash
idf.py monitor
```

Or use any serial terminal (PuTTY, Arduino IDE Serial Monitor) at 921600 baud on the same COM port.

Expected output after boot:

```
ESP32-S3 CSI Node -- Node ID: 1
WiFi STA initialized, connecting to SSID: RuView-24
Connected to WiFi
CSI streaming active -> 192.168.1.100:5500
```

If you see `WiFi connecting...` looping:
- Verify `RuView-24` is broadcasting (check router admin page)
- Verify the password in menuconfig is correct
- Verify the SSID is 2.4GHz only — the S3 cannot connect to 5GHz or WiFi 6/7 BSSes

Exit monitor with `Ctrl+]`.

On the Pi, verify packets are arriving:

```bash
timeout 10 python3 -c "
import socket
s = socket.socket(socket.AF_INET, socket.SOCK_DGRAM)
s.bind(('0.0.0.0', 5500))
s.settimeout(2)
count = 0
while True:
    try:
        data, addr = s.recvfrom(4096)
        count += 1
        print(f'Packet {count}: {len(data)} bytes from {addr}')
        if count >= 5:
            break
    except socket.timeout:
        print('Timeout — no packets received')
        break
"
```

Expected: 5 packets within 10 seconds.

> **Note:** At this point the node is using the compiled-in Kconfig defaults for Node ID,
> target IP, and UDP port. Provision it in Step 7.5 before relying on those values.

---

## 7.5. Provision Node 1

With Node 1 still connected via USB, write the node-specific config (Node ID, target IP,
UDP port, WiFi credentials) to the NVS partition without reflashing the firmware binary:

```bash
python firmware/provision.py \
    --port COM7 \
    --node-id 1 \
    --ssid RuView-24 \
    --password YOUR_PASSWORD \
    --target-ip 192.168.1.100 \
    --target-port 5500
```

Replace `COM7`, `YOUR_PASSWORD`, and `192.168.1.100` with your actual values.

| Flag | What it does |
|---|---|
| `--port` | Serial port connected to the ESP32 |
| `--node-id` | Node ID written to NVS (1 = left bedside, 2 = right ledge) |
| `--ssid` | WiFi SSID written to NVS (overrides compiled-in default) |
| `--password` | WiFi password written to NVS |
| `--target-ip` | Pi IP address the node streams CSI data to |
| `--target-port` | UDP port (default 5500, matches `server/config.py`) |

The device **does not** need to be in download mode for an NVS-only flash.

After provisioning, power-cycle the ESP32 and confirm the serial monitor shows:

```
ESP32-S3 CSI Node -- Node ID: 1
WiFi STA initialized, connecting to SSID: RuView-24
Connected to WiFi
CSI streaming active -> 192.168.1.100:5500
```

> **Cate School variant (Pi hotspot)**
>
> At Cate School, the Pi acts as an access point on `10.42.0.1`.
> Use this provision command instead:
> ```bash
> python firmware/provision.py \
>     --port COM7 \
>     --node-id 1 \
>     --ssid Basecamp-Pi \
>     --password YOUR_PASSWORD \
>     --target-ip 10.42.0.1 \
>     --target-port 5500
> ```

---

## 8. Flash and Provision — Node 2

Node 2 uses the **same firmware binary** as Node 1 — no rebuild is needed. Connect Node 2,
put it into download mode (hold BOOT, press RESET, release BOOT), and flash:

```bash
./firmware/flash.sh 2 COM8
```

Replace `COM8` with Node 2's actual port (use a different port to Node 1 if both are connected).

Then provision Node 2 (no download mode needed):

```bash
python firmware/provision.py \
    --port COM8 \
    --node-id 2 \
    --ssid RuView-24 \
    --password YOUR_PASSWORD \
    --target-ip 192.168.1.100 \
    --target-port 5500
```

Power-cycle Node 2 and confirm the serial monitor shows `Node ID: 2` and the correct target IP.

Place Node 2 on the right ledge at mattress height. Route the 3–5m USB-C cable along the skirting board to the powered USB hub.

---

## 9. Verify Both Nodes Simultaneously

With both nodes powered and connected to `RuView-24`, verify two distinct source IPs are streaming to the Pi:

```bash
timeout 15 python3 -c "
import socket, time
from collections import defaultdict
s = socket.socket(socket.AF_INET, socket.SOCK_DGRAM)
s.bind(('0.0.0.0', 5500))
s.settimeout(2)
sources = defaultdict(int)
end = time.time() + 10
while time.time() < end:
    try:
        data, addr = s.recvfrom(4096)
        sources[addr[0]] += 1
    except socket.timeout:
        pass
for ip, count in sources.items():
    print(f'{ip}: {count} packets')
print(f'Total sources: {len(sources)}')
"
```

Expected: two IPs, each with ~20 packets. If only one IP appears, the second node is not connecting to `RuView-24` — check its serial output.

---

## 10. Flash Scripts

To avoid reconstructing commands in HK, save these as `firmware/flash_node1.bat` and `firmware/flash_node2.bat`. Edit the COM port and Pi IP before use.

**flash_node1.bat**
```bat
@echo off
echo Flashing Node 1 -- make sure ESP32-S3 is in download mode (hold BOOT, press RESET)
python -m esptool --chip esp32s3 --port COM7 --baud 460800 ^
  --before default-reset --after hard-reset ^
  write-flash --flash-mode dio --flash-freq 80m --flash-size 16MB ^
  0x0     active_sta\build\bootloader\bootloader.bin ^
  0x8000  active_sta\build\partition_table\partition-table.bin ^
  0x10000 active_sta\build\esp32-csi-node.bin
pause
```

**flash_node2.bat** — identical, points to Node 2 build directory (rebuild after changing Node ID to 2 in menuconfig).

---

## Common Issues

| Symptom | Likely cause | Fix |
|---|---|-----|
| `A fatal error occurred: Failed to connect` | Not in download mode | Hold BOOT, press RESET, release BOOT, retry immediately |
| `No serial port found` | Wrong COM port or driver missing | Device Manager → check CP210x or CH340 driver is installed |
| `WiFi connecting...` loop | Wrong SSID/password, or 5GHz band | Verify RuView-24 is 2.4GHz legacy; check password in menuconfig |
| No UDP packets on Pi | Wrong UDP target IP, firewall | Verify Pi's IP matches menuconfig; check `ufw status` on Pi |
| Packets from only 1 node | Node 2 not connected | Check Node 2 serial output; verify Node ID was changed and reflashed |
| CSI data looks wrong / all zeros | FreeRTOS tick rate at default 100Hz | Set to 1000Hz in menuconfig, rebuild |
| `--flash-size detect` shows 4MB | Wrong flash size flag | Use `--flash-size 16MB` explicitly for N16R8 |
| Node ID in serial output is wrong | provision.py not run yet or NVS not picked up | Run provision.py, power-cycle, check serial output |
| `provision.py: module not found` | esp-idf-nvs-partition-gen not installed | `pip install esp-idf-nvs-partition-gen` |

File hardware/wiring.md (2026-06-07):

# Wiring reference

All connections are on the Raspberry Pi 4. The prototype uses an 830-point breadboard with Dupont jumper wires. All sensors are purchased as breakout boards with pre-soldered headers.

## I2C bus (GPIO 2 and GPIO 3)

Four environmental sensors share a single I2C bus. No additional wiring complexity beyond connecting each sensor to the same two data pins.

| Sensor | VCC | GND | SDA | SCL |
|---|-----|-----|-----|-----|
| SHT40 | 3.3V | GND | GPIO 2 | GPIO 3 |
| BH1750 | 3.3V | GND | GPIO 2 | GPIO 3 |
| SCD40 | 3.3V | GND | GPIO 2 | GPIO 3 |
| SGP40 | 3.3V | GND | GPIO 2 | GPIO 3 |

All four sensors can share the same physical SDA and SCL lines because I2C is an addressable bus. Each sensor has a unique I2C address so there are no conflicts.

I2C addresses for reference:
- SHT40: 0x44
- BH1750: 0x23 (or 0x5C if ADDR pin is high)
- SCD40: 0x62
- SGP40: 0x59

## I2S (INMP441 microphone)

| INMP441 pin | Pi GPIO | Notes |
|---|---|---|
| VDD | 3.3V | |
| GND | GND | |
| SCK | GPIO 18 | Bit clock |
| WS | GPIO 19 | Word select (left/right clock) |
| SD | GPIO 20 | Serial data out |
| L/R | GND | Sets microphone to left channel |

Enable I2S in /boot/config.txt and install an appropriate ALSA/device-tree overlay for the INMP441; set dtparam=i2s=on.

## UART (HLK-LD2410C radar)

| LD2410C pin | Pi GPIO | Notes |
|---|---|---|
| VCC | 5V | Radar requires 5V, not 3.3V |
| GND | GND | |
| TX | GPIO 15 (RXD) | Radar TX to Pi RX |
| RX | GPIO 14 (TXD) | Radar RX to Pi TX |

The LD2410C outputs presence detection, moving and still target states, distance per gate, and energy levels over UART. It does not output a respiration waveform. Its role in this project is bed presence detection, bed entry and exit timestamps, and gross micro-motion detection. Breathing rate is derived from CSI and audio only.

The default baud rate is 256000, which is non-standard and requires the Pi's full hardware UART rather than the mini-UART. The Pi 4 maps the full hardware UART to Bluetooth by default, so you have two options. The simpler option is to disable Bluetooth entirely by adding dtoverlay=disable-bt to /boot/config.txt. The alternative is to remap the hardware UART away from Bluetooth using dtoverlay=miniuart-bt, which keeps Bluetooth functional but on the less reliable mini-UART.

In addition to the baud rate setup, disable the Pi serial console so the UART is free for the radar: run sudo raspi-config, go to Interface Options, Serial Port, disable login shell over serial, enable the serial port hardware. The radar will then be available at /dev/ttyAMA0.

## SPI (2.8 inch touchscreen)

| Screen pin | Pi GPIO | Notes |
|---|---|---|
| VCC | 3.3V | |
| GND | GND | |
| CS | GPIO 8 (CE0) | Chip select |
| RESET | GPIO 25 | |
| DC | GPIO 24 | Data/command select |
| MOSI | GPIO 10 (MOSI) | |
| SCK | GPIO 11 (SCLK) | |
| LED | 3.3V | Backlight, always on |
| MISO | GPIO 9 (MISO) | Touch input only |
| T_CS | GPIO 7 (CE1) | Touch chip select |
| T_CLK | GPIO 11 (SCLK) | Shared with display |
| T_DIN | GPIO 10 (MOSI) | Shared with display |
| T_DO | GPIO 9 (MISO) | Shared with display |
| T_IRQ | GPIO 17 | Touch interrupt (optional) |

Enable SPI in /boot/config.txt by adding: dtparam=spi=on

The display and touch controller share the MOSI, MISO, and SCLK lines, using CE0 and CE1 as separate chip selects. If adding another SPI device in future, a third chip select pin will be needed and careful chip select management is required to avoid bus conflicts.

## ESP32-S3 nodes

The ESP32 nodes do not connect to the Pi via GPIO. They connect over WiFi on the dedicated RuView-24 2.4GHz SSID and stream raw CSI data to the Pi via UDP. Each node is powered independently via USB-C.

Node 1 (bedroom left): bedside table, powered from left wall socket
Node 2 (bedroom right): ledge at mattress height, powered via 3-5m USB-C cable routed along skirting board from left wall sockets

### Router settings for CSI reliability

On the ASUS router, apply these settings to the RuView-24 2.4GHz SSID:
- Disable airtime fairness (AirTime Fairness / ATF)
- Disable Smart Connect (band steering)
- Disable band steering

## Power

All sensors run on 3.3V from the Pi's 3.3V pin except the LD2410C radar which requires 5V. The Pi's 3.3V rail can comfortably supply all four I2C sensors and the INMP441 simultaneously. Total current draw from the 3.3V rail is well within the Pi 4's 500mA limit.

The Pi is powered from the official 5V/3A USB-C supply. The powered USB hub is powered independently and supplies both ESP32 nodes.

## GPIO pin summary

| GPIO | Function |
|---|---|
| 2 | I2C SDA (all environmental sensors) |
| 3 | I2C SCL (all environmental sensors) |
| 7 | SPI CE1 (touchscreen touch) |
| 8 | SPI CE0 (touchscreen display) |
| 9 | SPI MISO |
| 10 | SPI MOSI |
| 11 | SPI SCLK |
| 14 | UART TXD (radar RX) |
| 15 | UART RXD (radar TX) |
| 17 | Touch IRQ (optional) |
| 18 | I2S BCK (microphone) |
| 19 | I2S LRCK (microphone) |
| 20 | I2S DIN (microphone) |
| 24 | SPI DC (touchscreen) |
| 25 | SPI RESET (touchscreen) |

## /boot/config.txt changes required

Add the following lines:

dtparam=i2c_arm=on
dtparam=i2s=on
dtparam=spi=on
dtoverlay=disable-bt

Then disable the serial console via raspi-config as described in the UART section above. Reboot before testing any sensors.

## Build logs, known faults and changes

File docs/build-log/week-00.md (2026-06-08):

# Week 00: Software design and build (pre-hardware phase)

This entry covers the period before any hardware existed. The entire software stack was designed and built against simulated data before a single component was ordered. The goal was to arrive at hardware with a complete, tested pipeline so that the first real sensor readings could flow straight into a working system rather than into a half-finished one. That goal was mostly achieved, with a few things that will clearly need adjustment once real signals arrive.

## What was built

- `server/logger.py`: the overnight daemon that reads all four I2C environmental sensors every 30 seconds and writes to SQLite; the BH1750 runs at 1 Hz for the full 30-second window so the logger records both mean and maximum lux.
- `server/presence.py`: the overnight daemon that parses LD2410C radar UART frames, writes bed entry and exit events, and fires the morning batch job on wake detection after a minimum sleep duration.
- `server/audio.py`: the overnight audio chunker that classifies 30-second microphone windows as silence, ambient, or snoring using energy thresholds and a bandpass check in the 60 to 500 Hz snore frequency range.
- `pipeline/csi.py`: the CSI feature extraction module that reads 20 Hz cross-subcarrier variance from the database, applies bandpass and high-pass filters, and extracts breathing rate, breathing regularity, and movement power per 30-second window.
- `pipeline/features.py`: the feature engineering step that aggregates all overnight signals into a fixed-size feature vector for scoring.
- `pipeline/staging.py`: the three-class sleep stage classifier with a physics-grounded heuristic layer that runs from night one and a Random Forest personalisation layer that activates after 14 nights.
- `pipeline/score.py`: the weighted recovery score calculator (architecture 40%, continuity 25%, breathing 20%, environment 15%).
- `pipeline/attribution.py`: the SHAP-based attribution module that identifies which features drove the recovery score up or down.
- `pipeline/anomaly.py`: the anomaly detector that uses MAD z-score for the first 60 nights and switches to Isolation Forest thereafter.
- `pipeline/batch.py`: the seven-step morning orchestrator that runs the full pipeline in sequence and continues on per-step failure.
- `pipeline/simulate.py`: a synthetic data generator that inserts realistic overnight sensor data into the database, used as the development target for everything above.
- `pipeline/report.py`: the report generator that formats the morning summary and pushes it via ntfy.
- `server/sleepmode.py`: the central state machine that manages the five-state sleep lifecycle (idle, bedtime prompt, recording, morning, recovery) and drives the touchscreen.
- `server/screen.py`: the touchscreen UI controller with three layouts rendered to a 240x320 pygame surface; touch input uses hit-rects in screen coordinate space.
- `pi_setup.sh`: the Raspberry Pi setup script covering apt packages, Python venv, boot config, I2C/SPI/UART configuration, systemd service installation, and database initialisation.
- `server/calibrate_scd40.py`: a standalone calibration tool for the SCD40 CO2 sensor using direct I2C protocol with CRC-8 verification.
- A full set of architecture decision records in `docs/adr/` covering every significant design choice.

## Key decisions made

**Three-class staging instead of five-class.** The original plan included five-class staging matching clinical PSG terminology. I dropped N1 and N2 as separate classes early, after reading the literature on what WiFi CSI can and cannot distinguish. N1 and N2 differ primarily in EEG signature; their respiration and motion profiles are nearly identical. A system that claims to separate them from radio signals is presenting noise as signal. Three classes (wake, deep, light and REM combined) maps to what the hardware can actually see: movement power for wake, slow regular breathing for deep, everything else for light and REM.

**Batch processing in the morning instead of real-time inference overnight.** Running ML inference continuously during the night would heat the Pi, increase power draw, and add complexity with no benefit, since nobody reads sleep staging data until morning anyway. The entire analysis runs in a single batch job after bed exit is detected, which also means the full overnight dataset is available for context-aware processing (smoothing, run detection, session-level metrics) rather than having to process each window in isolation.

**ESP32-CSI-Tool with a custom Python layer instead of RuView.** RuView has a known JSONL model loading bug that falls back to heuristic mode silently. More importantly, using RuView would mean the processing pipeline is opaque; every layer of the CSI processing in this project is code I wrote and understand. ESP32-CSI-Tool is battle-tested firmware for raw CSI extraction, and the custom Python layer (bandpass FFT pipeline in `pipeline/csi.py`) is more straightforward to debug and extend than Rust code I did not write.

**SQLite with a single local file instead of a remote database.** The system runs overnight disconnected from any cloud service; a network outage should not affect data collection. SQLite with `row_factory = sqlite3.Row` throughout is simple, fast enough for this data volume, and produces a single file that is easy to back up. The schema is versioned via `migrate_schema()` so adding columns does not require recreating the database.

**Two-phase staging classifier with heuristic-first design.** The heuristic layer needed to produce useful output from night one, before any personal data existed to train on. This meant designing rules grounded in physiology rather than statistics: presence check, movement threshold, breathing rate range and regularity for deep sleep, breathing irregularity and snoring for REM within the light class. The Random Forest layer is additive and blends in gradually (60/40 heuristic/ML before 30 nights, 40/60 after) so there is no cliff edge where the model suddenly changes behaviour.

## What was hard

The CORS configuration between Flask and the Vite development server took longer than expected. Flask-CORS needs to allow both the development origin (localhost:5173) and the production path, and the order of middleware registration matters. The fix was straightforward once the issue was identified, but the error messages from the browser were not helpful for diagnosing the root cause.

The `simulate_night()` function in `pipeline/simulate.py` initially returned a dict of session data rather than a session ID. Several downstream tests called `classify_session(simulate_night(...))` and broke when the signature changed. This was a simple interface mismatch but it required touching every test file. The fix was to make `simulate_night()` consistently return an integer session ID and let callers query the database for anything else they need.

The CSI bandpass filter design required careful handling of null subcarriers and pilot subcarriers in the cross-subcarrier variance signal. The raw ESP32 CSI output includes subcarriers that are always zero (null) or always known (pilot), and including them inflates the variance signal and distorts the FFT. The pipeline zeros those indices before computing the variance to avoid contaminating the breathing rate extraction.

## What changed from the original plan

**Focus classifier dropped.** An early plan included a real-time attention and focus classifier for daytime use, separate from the sleep pipeline. It was dropped because it would have required a separate sensor setup and was orthogonal to the core sleep analysis goal. The project scope is now strictly overnight.

**SGP30 replaced by SGP40.** The original sensor list included the SGP30 for VOC monitoring. The SGP40 uses a proprietary Sensirion algorithm that outputs a VOC index (0 to 500) rather than raw equivalent CO2, which is more directly useful for environmental scoring. The SGP40 also has better long-term stability. The I2C address changed from 0x58 to 0x59 and the driver API is different, but the integration was straightforward.

**ADS1115 ADC removed.** An analog-to-digital converter was on the early parts list for possible analog sensor additions. Nothing in the current design uses analog inputs; the Pi has no onboard ADC and the sensors chosen are all I2C or I2S. The ADS1115 was removed to simplify the BOM.

## What the simulated data looks like

Running `pipeline/simulate.py` followed by `pipeline/batch.py` produces a complete morning report in about two seconds on a development machine. Ten integration test runs across different quality parameters produced recovery scores ranging from 68 to 88, with the environment score consistently low due to the simulated CO2 peaking above 1200 ppm (reflecting a room with poor ventilation in the simulation parameters). Deep sleep proportion in the simulated classifier comes in lower than ground truth because the synthetic movement noise uses an exponential distribution that pushes roughly half of deep-sleep windows above the movement threshold. This is a known limitation of the simulated data rather than a bug in the classifier, and is documented in the test comments.

## What comes next

When hardware arrives, the first task is calibration: verifying the SCD40 reads close to outdoor atmospheric CO2 (around 415 to 420 ppm), running the SGP40 burn-in overnight, and confirming the BH1750 and SHT40 are reading sensibly. The radar will need its presence and absence thresholds checked against real bed geometry. The CSI pipeline will almost certainly need adjustment once real subcarrier data arrives; the filter parameters were chosen based on the literature but may need tuning for the specific room geometry and mattress type. The touchscreen layout was designed for a 240x320 IPS panel but has only been tested in pygame mock mode. All of this is expected and is why the simulate-first approach was worth the investment upfront.

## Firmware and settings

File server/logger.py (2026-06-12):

"""
Sensor logger daemon -- reads all four environmental sensors every 30 seconds
and writes one row to sensor_readings. Runs overnight on the Pi.
"""
import os
import sys
import signal
import threading
import time
import logging
import logging.handlers
from datetime import datetime

sys.path.insert(0, os.path.join(os.path.dirname(__file__), ".."))
from server.config import (
    DB_PATH, I2C_BUS, SHT40_ADDR, BH1750_ADDR, SCD40_ADDR, SGP40_ADDR,
    MOCK_HARDWARE, WATCHDOG_INTERVAL_SECONDS, HEARTBEAT_INTERVAL_SECONDS,
)
from server.db import init_db, get_connection

# ---------------------------------------------------------------------------
# Hardware imports (optional -- fall back to mock if unavailable)
# ---------------------------------------------------------------------------
try:
    import smbus2
    _SMBUS_AVAILABLE = True
except ImportError:
    _SMBUS_AVAILABLE = False

try:
    from sensirion_i2c_driver import I2cConnection, LinuxI2cTransceiver
    from sensirion_i2c_scd4x import Scd4xI2cDevice
    _SCD4X_LIB = True
except ImportError:
    _SCD4X_LIB = False

try:
    from sensirion_i2c_sgp4x import Sgp40I2cDevice
    _SGP40_LIB = True
except ImportError:
    _SGP40_LIB = False

try:
    from voc_algorithm import VocAlgorithm
    _VOC_ALG = True
except ImportError:
    _VOC_ALG = False

# ---------------------------------------------------------------------------
# Logging setup
# ---------------------------------------------------------------------------
os.makedirs("logs", exist_ok=True)
_handler = logging.handlers.RotatingFileHandler(
    "logs/logger.log", maxBytes=5 * 1024 * 1024, backupCount=3
)
_handler.setFormatter(logging.Formatter("%(asctime)s %(levelname)s %(message)s"))
_stream = logging.StreamHandler()
_stream.setFormatter(logging.Formatter("%(asctime)s %(levelname)s %(message)s"))
log = logging.getLogger("logger")
log.setLevel(logging.INFO)
log.addHandler(_handler)
log.addHandler(_stream)

# ---------------------------------------------------------------------------
# Mock state (shared across calls for realistic drift)
# ---------------------------------------------------------------------------
_mock = {
    "temp": 20.0,
    "humidity": 65.0,
    "co2": 420.0,
    "voc": 100.0,
    "start_time": None,
}


def _mock_readings():
    import random
    import math

    now = time.time()
    if _mock["start_time"] is None:
        _mock["start_time"] = now

    elapsed_hours = (now - _mock["start_time"]) / 3600.0

    _mock["temp"] += random.uniform(-0.05, 0.05)
    _mock["temp"] = max(19.0, min(21.0, _mock["temp"]))

    _mock["humidity"] += random.uniform(-0.1, 0.1)
    _mock["humidity"] = max(60.0, min(70.0, _mock["humidity"]))

    _mock["co2"] = 420.0 + elapsed_hours * 200.0 + random.uniform(-20, 20)
    _mock["co2"] = max(380.0, _mock["co2"])

    _mock["voc"] += random.uniform(-2, 2)
    _mock["voc"] = max(80.0, min(120.0, _mock["voc"]))

    # Light near zero overnight; brief spike around 3 am (simulated as 3h after start)
    light = 0.0
    if 2.9 <= elapsed_hours <= 3.1:
        light = 50.0 + random.uniform(0, 20)
    else:
        light = random.uniform(0, 0.5)

    import random as _r
    max_lux = round(light + _r.uniform(0, light * 0.2 + 0.1), 2)
    return {
        "temperature": round(_mock["temp"], 2),
        "humidity": round(_mock["humidity"], 2),
        "co2_ppm": round(_mock["co2"], 1),
        "voc_index": round(_mock["voc"], 1),
        "light_lux": round(light, 2),
        "max_lux": max_lux,
    }


# ---------------------------------------------------------------------------
# Real sensor reads
# ---------------------------------------------------------------------------

def _crc8(data):
    crc = 0xFF
    for byte in data:
        crc ^= byte
        for _ in range(8):
            crc = ((crc << 1) ^ 0x31) & 0xFF if crc & 0x80 else (crc << 1) & 0xFF
    return crc


def _read_sht40(bus):
    bus.write_byte(SHT40_ADDR, 0xFD)
    time.sleep(0.01)
    data = bus.read_i2c_block_data(SHT40_ADDR, 0, 6)
    if _crc8(data[0:2]) != data[2] or _crc8(data[3:5]) != data[5]:
        raise ValueError("SHT40 CRC mismatch")
    raw_t = (data[0] << 8) | data[1]
    raw_h = (data[3] << 8) | data[4]
    temp = -45.0 + 175.0 * raw_t / 65535.0
    hum = -6.0 + 125.0 * raw_h / 65535.0
    return round(temp, 2), round(max(0.0, min(100.0, hum)), 2)


def _read_bh1750(bus):
    bus.write_byte(BH1750_ADDR, 0x10)
    time.sleep(0.18)
    data = bus.read_i2c_block_data(BH1750_ADDR, 0, 2)
    raw = (data[0] << 8) | data[1]
    return round(raw / 1.2, 2)


def _read_scd40_direct(bus):
    # Stop any ongoing measurement first
    bus.write_i2c_block_data(SCD40_ADDR, 0x3F, [0x86])
    time.sleep(0.5)
    # Start periodic measurement
    bus.write_i2c_block_data(SCD40_ADDR, 0x21, [0xB1])
    time.sleep(5.0)
    for _ in range(20):
        bus.write_i2c_block_data(SCD40_ADDR, 0xE4, [0xB8])
        time.sleep(0.01)
        rdy = bus.read_i2c_block_data(SCD40_ADDR, 0, 3)
        if rdy[1] & 0x07:
            break
        time.sleep(1.0)
    bus.write_i2c_block_data(SCD40_ADDR, 0xEC, [0x05])
    time.sleep(0.01)
    data = bus.read_i2c_block_data(SCD40_ADDR, 0, 9)
    if _crc8(data[0:2]) != data[2]:
        raise ValueError("SCD40 CO2 CRC mismatch")
    co2 = (data[0] << 8) | data[1]
    return float(co2)


def _read_sgp40_direct(bus):
    # Default compensation: T=25C encoded, RH=50% encoded
    comp = [0x66, 0x66, 0x93, 0x80, 0x00, 0xA2]
    bus.write_i2c_block_data(SGP40_ADDR, 0x26, [0x0F] + comp)
    time.sleep(0.03)
    data = bus.read_i2c_block_data(SGP40_ADDR, 0, 3)
    if _crc8(data[0:2]) != data[2]:
        raise ValueError("SGP40 CRC mismatch")
    raw = (data[0] << 8) | data[1]
    return float(raw)


# ---------------------------------------------------------------------------
# Undervoltage check (both ESP32 nodes now share the Pi's USB supply in v4)
# ---------------------------------------------------------------------------

def _check_undervoltage():
    try:
        import subprocess as _sp
        result = _sp.run(
            ["vcgencmd", "get_throttled"],
            capture_output=True, text=True, timeout=3,
        )
        val = result.stdout.strip()
        # get_throttled returns hex bitmask; bit 0 = currently under-voltage
        if "=" in val:
            bits = int(val.split("=")[1], 16)
            if bits & 0x1:
                log.warning(
                    "Pi undervoltage detected (vcgencmd get_throttled=%s). "
                    "Both ESP32 nodes share the Pi USB supply in v4 -- "
                    "verify the PSU is the official 5V/3A adapter and "
                    "the Node 2 cable is 20AWG or thicker.",
                    val,
                )
            else:
                log.info("Power supply OK (get_throttled=%s)", val)
    except Exception as e:
        log.debug("vcgencmd check skipped: %s", e)


# ---------------------------------------------------------------------------
# Daemon state
# ---------------------------------------------------------------------------
_running = True
_bus = None
_voc_algorithm = None


def _handle_sigterm(signum, frame):
    global _running
    log.info("SIGTERM received, shutting down")
    _running = False


def _init_hardware():
    global _bus, _voc_algorithm
    sensors_ok = []
    sensors_fail = []

    if not _SMBUS_AVAILABLE:
        log.warning("smbus2 not available -- hardware init skipped")
        return sensors_ok, sensors_fail

    try:
        _bus = smbus2.SMBus(I2C_BUS)
        sensors_ok.append("I2C bus")
    except Exception as e:
        log.error(f"Failed to open I2C bus: {e}")
        return sensors_ok, sensors_fail

    for name, addr, probe_cmd in [
        ("SHT40", SHT40_ADDR, 0xFD),
        ("BH1750", BH1750_ADDR, 0x10),
    ]:
        try:
            _bus.write_byte(addr, probe_cmd)
            sensors_ok.append(name)
        except Exception as e:
            log.warning(f"{name} init failed: {e}")
            sensors_fail.append(name)

    for name, addr in [("SCD40", SCD40_ADDR), ("SGP40", SGP40_ADDR)]:
        sensors_ok.append(name)  # initialised on first read

    if _VOC_ALG:
        _voc_algorithm = VocAlgorithm()

    return sensors_ok, sensors_fail


def _read_all_sensors():
    results = {
        "temperature": None,
        "humidity": None,
        "co2_ppm": None,
        "voc_index": None,
        "light_lux": None,
        "max_lux": None,
    }

    if MOCK_HARDWARE or not _SMBUS_AVAILABLE or _bus is None:
        return _mock_readings()

    try:
        temp, hum = _read_sht40(_bus)
        results["temperature"] = temp
        results["humidity"] = hum
    except Exception as e:
        log.error(f"SHT40 read error: {e}")

    try:
        results["light_lux"] = _read_bh1750(_bus)
    except Exception as e:
        log.error(f"BH1750 read error: {e}")

    try:
        results["co2_ppm"] = _read_scd40_direct(_bus)
    except Exception as e:
        log.error(f"SCD40 read error: {e}")

    try:
        raw_voc = _read_sgp40_direct(_bus)
        if _voc_algorithm is not None:
            results["voc_index"] = float(_voc_algorithm.process(raw_voc))
        else:
            results["voc_index"] = raw_voc
    except Exception as e:
        log.error(f"SGP40 read error: {e}")

    return results


def _write_heartbeat():
    try:
        conn = get_connection(DB_PATH)
        try:
            conn.execute(
                """INSERT INTO service_heartbeats (service_name, last_heartbeat, status)
                   VALUES ('logger', ?, 'running')
                   ON CONFLICT(service_name) DO UPDATE
                   SET last_heartbeat=excluded.last_heartbeat, status=excluded.status""",
                (time.time(),),
            )
            conn.commit()
        finally:
            conn.close()
    except Exception as e:
        log.debug(f"Heartbeat write failed: {e}")


def _write_reading(readings):
    ts = datetime.utcnow().isoformat()
    sql = """
        INSERT INTO sensor_readings
        (timestamp, temperature, humidity, co2_ppm, voc_index, light_lux, max_lux)
        VALUES (?, ?, ?, ?, ?, ?, ?)
    """
    params = (
        ts,
        readings["temperature"],
        readings["humidity"],
        readings["co2_ppm"],
        readings["voc_index"],
        readings["light_lux"],
        readings.get("max_lux"),
    )
    for attempt in range(2):
        try:
            conn = get_connection(DB_PATH)
            try:
                conn.execute(sql, params)
                conn.commit()
            finally:
                conn.close()
            return
        except Exception as e:
            log.error(f"DB write failed (attempt {attempt + 1}): {e}")
            if attempt == 0:
                time.sleep(5)
    log.error("DB write failed after retry, dropping reading")


def _collect_bh1750_1hz(bus, n_samples=30):
    """
    Collect n_samples BH1750 readings at ~1 Hz.
    Returns (mean_lux, max_lux). Falls back to a single reading on error.
    """
    readings = []
    for _ in range(n_samples):
        try:
            lux = _read_bh1750(bus)
            readings.append(lux)
        except Exception as e:
            log.debug(f"BH1750 1Hz sample error: {e}")
        time.sleep(1.0)
    if not readings:
        return None, None
    return round(sum(readings) / len(readings), 2), round(max(readings), 2)


def run():
    global _running
    if threading.current_thread() is threading.main_thread():
        signal.signal(signal.SIGTERM, _handle_sigterm)

    init_db(DB_PATH)

    if MOCK_HARDWARE:
        log.info("Starting sensor logger in MOCK mode")
        print("Sensor logger started -- MOCK mode")
    else:
        _check_undervoltage()
        sensors_ok, sensors_fail = _init_hardware()
        msg = f"Sensor logger started -- OK: {sensors_ok}"
        if sensors_fail:
            msg += f"  FAILED: {sensors_fail}"
        log.info(msg)
        print(msg)

    try:
        import sdnotify as _sdnotify
        _notifier = _sdnotify.SystemdNotifier()
    except ImportError:
        _notifier = None

    last_watchdog = time.monotonic()
    last_heartbeat = time.monotonic()

    while _running:
        # --- BH1750 1Hz collection (takes ~30s, matches the loop cadence) ---
        if not MOCK_HARDWARE and _SMBUS_AVAILABLE and _bus is not None:
            mean_lux, max_lux = _collect_bh1750_1hz(_bus, n_samples=30)
        else:
            mean_lux, max_lux = None, None
            # In mock mode still wait the 30-second window
            for _ in range(30):
                if not _running:
                    break
                time.sleep(1)

        readings = _read_all_sensors()
        # Overwrite light_lux with the mean from 1Hz collection if available
        if mean_lux is not None:
            readings["light_lux"] = mean_lux
            readings["max_lux"] = max_lux
        _write_reading(readings)
        log.debug(f"Reading: {readings}")

        now_mono = time.monotonic()
        if now_mono - last_watchdog >= WATCHDOG_INTERVAL_SECONDS:
            last_watchdog = now_mono
            try:
                if _notifier:
                    _notifier.notify("WATCHDOG=1")
            except Exception:
                pass
        if now_mono - last_heartbeat >= HEARTBEAT_INTERVAL_SECONDS:
            last_heartbeat = now_mono
            _write_heartbeat()

    log.info("Sensor logger stopped")


if __name__ == "__main__":
    run()

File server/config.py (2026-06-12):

DB_PATH = "data/basecamp.db"
CSI_UDP_PORT = 5006
CSI_UDP_HOST = "0.0.0.0"
AUDIO_SAMPLE_RATE = 16000
AUDIO_CHUNK_SECONDS = 30
SILENCE_THRESHOLD = 0.01
SNORE_THRESHOLD = 0.05
SNORE_FREQ_LOW = 60
SNORE_FREQ_HIGH = 500
RADAR_SERIAL_PORT = "/dev/ttyAMA0"
RADAR_BAUD_RATE = 256000
MIN_SLEEP_HOURS = 4
I2C_BUS = 1
SHT40_ADDR = 0x44
BH1750_ADDR = 0x23
SCD40_ADDR = 0x62
SGP40_ADDR = 0x59
DS3231_ADDR = 0x68   # RTC module; provides offline timekeeping (fake-hwclock must be disabled)
NTFY_TOPIC = "basecamp-recovery"
NTFY_SERVER = "https://ntfy.sh"
RECOVERY_WEIGHTS = {
    "architecture": 0.40,
    "continuity": 0.25,
    "breathing": 0.20,
    "environment": 0.15,
}

MOCK_HARDWARE = True

# Node power: both ESP32 nodes draw from Pi USB-A ports (no hub).
# Combined peak ~0.8A, within Pi 4's 1.2A USB budget.
NODE2_USB_POWER = True   # Node 2 powered from Pi USB-A via 5m 20AWG cable

# Screen and button GPIO
SCREEN_ROTATION = 90
SCREEN_BACKLIGHT_PIN = 22   # GPIO 22 (GPIO 24 is SPI DC -- conflicts with touchscreen)
BUTTON_PIN = 26

# Auto-wake: screen and glow LED come on at bed exit, off after idle
SCREEN_IDLE_TIMEOUT_S = 60   # seconds before backlight turns off after bed exit

# Recovery glow LED GPIO (RGB common-cathode, via resistors)
GLOW_R_PIN = 16
GLOW_G_PIN = 20
GLOW_B_PIN = 21

# Glow colour thresholds (score out of 100; divided by 10 for 0-10 display scale)
GLOW_GREEN_THRESHOLD = 70   # score >= 70 -> green (>=7/10)
GLOW_AMBER_THRESHOLD = 40   # score 40-69 -> amber (4-6.9/10); below 40 -> red

# Sleep mode timing
BEDTIME_WINDOW_START = 21
BEDTIME_WINDOW_END = 0
PRESENCE_ARM_MINUTES = 2
BEDTIME_PROMPT_TIMEOUT_MINUTES = 5
BEDTIME_SNOOZE_MINUTES = 30
AUTO_RECORD_MINUTES = 15
WAKE_ABSENCE_MINUTES = 15
WAKE_EARLIEST_HOUR = 5

# Pipeline / model
ANOMALY_MIN_NIGHTS = 60
AUDIO_RETENTION_DAYS = 7

# Watchdog / health
WATCHDOG_INTERVAL_SECONDS = 30
HEARTBEAT_INTERVAL_SECONDS = 60

# Sleep stage classifier thresholds
MOVEMENT_THRESHOLD_LOW  = 0.05
MOVEMENT_THRESHOLD_HIGH = 0.30
DEEP_BREATHING_MIN      = 10
DEEP_BREATHING_MAX      = 15
REGULARITY_THRESHOLD_HIGH = 0.70
REGULARITY_THRESHOLD_LOW  = 0.40
DEEP_RUN_MIN_WINDOWS    = 4
STAGING_MIN_NIGHTS_ML   = 14

# Touchscreen display
SCREEN_WIDTH       = 240
SCREEN_HEIGHT      = 320
SCREEN_SPI_PORT    = 0
SCREEN_SPI_DEVICE  = 0
SCREEN_DC_PIN      = 24
SCREEN_RESET_PIN   = 25
# SCREEN_BACKLIGHT_PIN = 22  (already defined above)
TOUCH_CS_PIN       = 7
TOUCH_IRQ_PIN      = 17
TOUCH_X_MIN        = 200
TOUCH_X_MAX        = 3800
TOUCH_Y_MIN        = 200
TOUCH_Y_MAX        = 3800
SCREEN_FPS         = 10
SCREEN_MOCK_SCALE  = 2

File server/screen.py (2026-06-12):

"""
Touchscreen UI controller for Basecamp -- 240×320 IPS SPI display (ILI9341/ST7789).

In mock mode (MOCK_HARDWARE=True) renders to a 480×640 pygame window so the UI
is fully interactive on a development machine.  All three layouts (IDLE,
BEDTIME_PROMPT, MORNING) are contained here.

sleepmode.py drives this module by calling:
  screen.tick()                       -- every second (clock / animation update)
  screen.get_pending_action()         -- every second (returns touch result or None)
"""
import os
import sys
import time
import logging

sys.path.insert(0, os.path.join(os.path.dirname(__file__), ".."))

log = logging.getLogger("screen")

# ── Color palette (all RGB tuples) ─────────────────────────────────────────────
_BG          = (5,   8,  16)
_WHITE       = (255, 255, 255)
_MUTED       = (153, 153, 153)   # 60 % white
_SECONDARY   = (102, 102, 102)   # 40 % white
_TEAL        = (0,   229, 160)
_AMBER       = (245, 166,  35)
_RED         = (255,  77, 109)
_CARD_BG     = (13,  17,  23)
_BORDER      = (26,  31,  46)
_TIMEOUT_BAR = (77,  77,  77)   # ~30 % white

# Component score accent colours
_ARCH_CLR = (123, 143, 247)
_CONT_CLR = _TEAL
_BRTH_CLR = (74,  144, 217)
_ENV_CLR  = _AMBER


def _score_color(score: float):
    if score >= 75:
        return _TEAL
    if score >= 50:
        return _AMBER
    return _RED


# ── Optional imports ───────────────────────────────────────────────────────────
try:
    import pygame as _pg
    _PYGAME_OK = True
except ImportError:
    _pg = None
    _PYGAME_OK = False

try:
    from PIL import Image as _PILImage
    _PIL_OK = True
except ImportError:
    _PIL_OK = False


class BasecampScreen:
    """
    Manages the 240×320 touchscreen display and touch input.

    Parameters
    ----------
    mock    : True renders to a 2× pygame window; False drives the SPI display
    db_path : SQLite path for IDLE sensor readings (defaults to config.DB_PATH)
    """

    W = 240
    H = 320
    _BEDTIME_TIMEOUT_S = 300.0   # 5 minutes

    def __init__(self, mock: bool = False, db_path: str = None):
        self.mock      = mock
        self._db_path  = db_path
        self._headless = False

        # pygame surfaces
        self._surface = None   # 240×320 offscreen (always rendered to)
        self._window  = None   # actual display window

        # Backlight
        self._backlight = False

        # Layout state
        self._current_layout    = None   # 'idle' | 'bedtime_prompt' | 'morning' | None
        self._prompt_start_time = None   # monotonic when BEDTIME_PROMPT shown
        self._dot_idx           = 0      # loading animation frame

        # Morning display data
        self._session_data = {}
        self._score        = None
        self._loading      = True

        # Sensor reading cache for IDLE
        self._last_sensor_mono = 0.0
        self._sensor_cache     = {}

        # Action / touch queues
        self._touch_queue    : list = []   # (x, y) from simulate_touch()
        self._pending_actions: list = []   # resolved action strings

        # Hit-rects (240×320 coordinate space)
        self._not_yet_rect = None
        self._yes_rect     = None
        self._log_rect     = None

        # Real-hardware GPIO / SPI
        self._gpio       = None
        self._bl_pin     = None
        self._gpio_ready = False
        self._spi_device = None

        self._init_pygame()
        self._init_gpio()
        self._init_spi()
        self._init_rects()

    # ── Initialisation ────────────────────────────────────────────────────────

    def _init_pygame(self):
        if not _PYGAME_OK:
            log.warning("pygame unavailable -- BasecampScreen running headless")
            self._headless = True
            return
        try:
            _pg.init()
            self._surface = _pg.Surface((self.W, self.H))
            self._surface.fill(_BG)

            if self.mock:
                try:
                    from server.config import SCREEN_MOCK_SCALE
                    scale = SCREEN_MOCK_SCALE
                except (ImportError, AttributeError):
                    scale = 2
                self._window = _pg.display.set_mode((self.W * scale, self.H * scale))
                _pg.display.set_caption("Basecamp Display")
            else:
                if not os.environ.get("DISPLAY"):
                    os.environ.setdefault("SDL_VIDEODRIVER", "fbcon")
                self._window = _pg.display.set_mode((self.W, self.H))
                _pg.display.set_caption("Basecamp")

            log.info("pygame display initialised (%s)",
                     "mock 480x640" if self.mock else "240x320")
        except Exception as e:
            log.error("pygame init failed: %s", e)
            self._headless = True

    def _init_gpio(self):
        if self.mock:
            return
        try:
            import RPi.GPIO as GPIO
            from server.config import SCREEN_BACKLIGHT_PIN
            GPIO.setmode(GPIO.BCM)
            GPIO.setup(SCREEN_BACKLIGHT_PIN, GPIO.OUT, initial=GPIO.LOW)
            self._gpio       = GPIO
            self._bl_pin     = SCREEN_BACKLIGHT_PIN
            self._gpio_ready = True
        except Exception:
            pass

    def _init_spi(self):
        if self.mock:
            return
        try:
            from luma.lcd.device import ili9341
            from luma.core.interface.serial import spi
            from server.config import (
                SCREEN_SPI_PORT, SCREEN_SPI_DEVICE,
                SCREEN_DC_PIN, SCREEN_RESET_PIN,
            )
            serial = spi(
                port=SCREEN_SPI_PORT,
                device=SCREEN_SPI_DEVICE,
                gpio_DC=SCREEN_DC_PIN,
                gpio_RST=SCREEN_RESET_PIN,
                bus_speed_hz=32_000_000,
            )
            self._spi_device = ili9341(serial, width=self.W, height=self.H)
            log.info("luma.lcd ILI9341 SPI display initialised")
        except Exception as e:
            log.debug("luma.lcd unavailable (%s) -- framebuffer only", e)
            self._spi_device = None

    def _init_rects(self):
        if not _PYGAME_OK:
            return
        # Hit-rects are pure data -- no display needed
        self._not_yet_rect = _pg.Rect(20, 170, 200, 50)   # x=20..220, y=170..220
        self._yes_rect     = _pg.Rect(20, 235, 200, 65)   # x=20..220, y=235..300
        self._log_rect     = _pg.Rect(0,  265, 240, 55)   # x=0..240,  y=265..320

    # ── Font helpers ──────────────────────────────────────────────────────────

    def _font(self, size: int, bold: bool = False, mono: bool = False):
        if not _PYGAME_OK or self._headless:
            return None
        try:
            family = "monospace" if mono else "sans"
            return _pg.font.SysFont(family, size, bold=bold)
        except Exception:
            try:
                return _pg.font.Font(None, size)
            except Exception:
                return None
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

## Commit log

2026-06-05 update BOM with real prices and SCD40 verification notes
2026-06-05 fix radar overclaim, add UART baud rate caveat, update README and ADRs
2026-06-05 build complete software foundation for simulated pipeline development
    - server/config.py: all config constants as specified
    - server/schema.sql + db.py: SQLite schema (8 tables) with init and helper functions
    - pipeline/simulate.py: generates realistic 7-8h sleep nights at 30s intervals;
    quality param (0-1) controls CO2, apneas, awakenings, snoring, and sleep regularity;
    uses cosine-based breathing rate formula to produce physiologically realistic
    stage separation (deep ~13 BPM, REM ~16 BPM)
    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
2026-06-05 Build complete software foundation for simulated pipeline development
    * build complete software foundation for simulated pipeline development
    - pipeline/features.py: extracts 20 features from raw sensor data including
    sleep stage proportions, apnea/snoring counts,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
2026-06-06 complete dashboard visual overhaul and critical bug fixes
    Critical fixes:
    - Add /scores endpoint to morning/app.py (latest score per session joined with
    sleep_sessions, ordered by bed_entry ASC) — Trends view now shows all nights
    regardless of whether a morning log entry exists
    - Apply 10-window mode filter to sleep stage classifications before rendering
    so the hypnogram bar shows consolidated blocks rather than per-sample stripes
    - Show bed entry/exit times ("22:30 → 05:30") under sleep duration in Last Night
    Functional improvements:
    - Morning log fetches /latest on load and shows last night's recovery score
    in teal at the top of the page
    - Slider values persist in localStorage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
2026-06-06 complete dashboard visual overhaul and critical bug fixes (#5)
    - Slider values persist in localSt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
2026-06-06 Dashboard fixes: Trends, Sleep charts, score glow, graph smoothing, hypnogram classifier (#7)
    * Fix Trends deduplication, add humidity/VOC charts, boost score glow, smooth graphs
    - Trends: use bed_entry.slice(5,10) for x-axis keys so each session is a
    distinct point even when multiple sessions share the same calendar date
    - Sleep view: add humidity (#a78bfa) and VOC index (#34d399) sparkline
    charts below temperature; downsample dense sensor readings to ~100 pts
    - ScoreRing: raise radial glow opacity from 13% to 25% (hex 40) and add
    blur(80px) filter for a visible halo effect behind the score number
    - All charts: switch curve type from monotone to basis for smoother lines
    https://clau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
2026-06-06 Add three overnight daemon files, CLAUDE.md, and supporting infrastructure
    - server/logger.py: SHT40/BH1750/SCD40/SGP40 sensor logger; reads every 30s,
    writes to sensor_readings; mock mode with realistic drift
    - server/presence.py: HLK-LD2410C radar watcher; state machine (ABSENT →
    PRESENT → IN_BED → POSSIBLE_EXIT → EXITED); triggers pipeline/batch.py on
    confirmed bed exit ≥ MIN_SLEEP_HOURS; hysteresis 3/5 frames
    - server/audio.py: INMP441 chunker; 30s chunks classified as silence/ambient/
    snore via RMS + bandpass energy; opus via ffmpeg (npz fallback); apnea
    detection on snore→silence transition
    - server/config.py: add MOCK_HARDWARE = True
    - server/schema.sql: relax sl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
    [audio.py, config.py, logger.py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]
2026-06-06 Add CSI processing pipeline with synthetic validation
    Builds the two-path CSI architecture (live ingestion daemon + morning
    batch feature extraction) and proves correctness with a test suite that
    recovers known breathing rates from synthetic data before any hardware
    is available.
    New files
    - pipeline/csi_synthetic.py: generates complex CSI matrices with
    embedded breathing at known BPM + movement bursts; shared by both
    the test suite and the ingestion daemon mock mode.
    - pipeline/csi.py: morning-batch feature extractor — reads the stored
    20 Hz csi_variance signal, runs per-window Butterworth bandpass +
    zero-padded FFT to extract breathing rate / regularity / movement
    power, perfo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
    [csi_ingest.py]
2026-06-07 add sleepmode state machine, implement 12 architecture review fixes
    - server/sleepmode.py: central state machine daemon (IDLE, BEDTIME_PROMPT,
    RECORDING, MORNING) with pygame screen, GPIO backlight/button, radar-based
    presence detection, session management, and batch pipeline orchestration
    - server/test_sleepmode.py: 7 integration tests (26 assertions, all passing)
    covering the full night lifecycle, recovery, bathroom trips, and auto-start
    Architecture review fixes:
    - Fix 1: pi_timestamp REAL added to radar_events, audio_chunks, csi_variance
    - Fix 2: status + created_at columns on sleep_sessions; migrate_schema() in db.py
    - Fix 3: recover_unfinished_sessions() in sleepmode.py startup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
    [config.py, db.py, logger.py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]
2026-06-07 add sleep stage classifier with heuristic + ML personalisation layer
    Implements pipeline/staging.py — a three-class (WAKE/DEEP/LIGHT_REM)
    sleep stage classifier with a two-phase design: a physics-grounded
    heuristic that runs from night 1, plus a RandomForest personalisation
    layer that activates after 14+ nights and blends in at 40–60% weight.
    - pipeline/staging.py: full classifier with _heuristic_single(),
    _apply_deep_run(), _apply_smoothing(), _apply_min_duration(),
    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
2026-06-08 add touchscreen UI controller with all three layouts
    Implements server/screen.py — BasecampScreen class for the 240x320 IPS SPI
    display. Renders IDLE (clock + env sensors), BEDTIME_PROMPT (yes/not-yet
    buttons with 5-min timeout bar), and MORNING (loading dots + score card with
    2x2 component grid). In mock mode renders to a 480x640 pygame window (2x
    scale); real hardware sends pixel buffer to SPI display via Pillow + luma.lcd.
    Touch detection uses hit-rects in 240x320 space with simulate_touch() for
    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
2026-06-08 add Pi setup script, hotspot config, and SCD40 calibration tool
    pi_setup.sh: single-shot setup for a fresh Pi OS Lite 64-bit install —
    13 steps covering apt packages, Python venv with hardware libs, boot
    config (I2C/SPI/I2S/UART), i2cdetect scan with per-address warnings,
    systemd service install with venv Python path substitution, DB init,
    and formatted reminders for router config, SCD40 calibration, and
    MOCK_HARDWARE. Root + Raspberry Pi pre-flight checks, idempotent where
    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
2026-06-09 Add nightly SQLite backup: script, systemd timer, pre-pipeline hook, and tests
    - server/backup.py: stdlib-only backup utility (shutil/sqlite3/pathlib); copies db
    to data/backups/basecamp_YYYYMMDD_HHMMSS.db, validates via sqlite_master read,
    enforces 30-file retention, sends ntfy push on failure
    - systemd/basecamp-backup.service: Type=oneshot service (timer-only, not enabled directly)
    - systemd/basecamp-backup.timer: OnCalendar=04:00 daily with Persistent=true
    - pipeline/batch.py: calls run_backup() as step 0 before pipeline steps; warns on
    failure but never aborts the pipeline
    - pi_setup.sh: copies *.timer files alongside *.service files; enables and starts
    basecamp-backup.timer (not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
    [backup.py, test_backup.py]
2026-06-09 Add adaptive personal thresholds: calibration, staging integration, and tests
    - server/schema.sql + db.py: new personal_thresholds table (movement_low/high,
    breathing_low/high/mean, is_active, nights_used, computed_at)
    - pipeline/calibrate.py: compute_thresholds() queries last 30 nights of CSI data,
    computes P25/P75 movement and mean±1.5σ breathing (clamped 8–25 BPM), deactivates
    the previous active row and writes a new one; returns None if < 7 nights
    - pipeline/staging.py: load_thresholds() reads the active row into a SimpleNamespace;
    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
2026-06-09 Add trend-aware SHAP analysis: slopes, z-scores, persistence, dashboard panel
    - server/schema.sql + db.py: feature_trends table (slope_7/14, mean_7, z_score,
    shap_direction, is_persistent per session per feature)
    - pipeline/trends.py: compute_trends() loads last 14 sessions from recovery_scores,
    sleep_sessions, sensor_readings, and sleep_stages; computes np.polyfit slopes,
    z-scores clamped ±4, majority-sign SHAP direction via keyword match; writes
    feature_trends replacing existing rows; returns persistent factors sorted by
    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
2026-06-09 Add CSI signal quality marker and screen demo mode
    Part 1 — Signal quality marker:
    - Add signal_quality (REAL) to csi_variance and csi_readings tables; add
    low_confidence_pct (REAL) to recovery_scores; db.py migration covers all three
    - pipeline/csi.py: compute_signal_quality() uses Hanning-windowed FFT peak-to-noise
    ratio in the 0.1–0.5 Hz breathing band, mapped via sigmoid (threshold ratio 4.0)
    - pipeline/features.py: filters low-confidence windows (quality < 0.5) from
    breathing_rate_mean and breathing_regularity; adds csi_low_confidence_pct and
    csi_quality_mean features; nulls out breathing metrics when > 80% low confidence
    - pipeline/staging.py: NaN breathing rate no longer f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
    [db.py, screen.py]
2026-06-09 Add crash notifications via ntfy for all five daemons
    - server/crash_notify.py: stdlib-only module with notify_crash() and
    notify_recovery(); tracks failure counts in SQLite; escalates to high
    priority / rotating_light tag at 3+ failures; __main__ entrypoint for
    systemd OnFailure
    - server/test_crash_notify.py: 13 unit tests covering priority levels,
    DB increment/reset, network error handling, recovery gating
    - server/schema.sql, server/db.py: add daemon_failures table (UNIQUE on
    daemon_name+date for nightly count reset)
    - systemd/basecamp-notify@.service: oneshot template service invoked by
    systemd via OnFailure
    - systemd/basecamp-{logger,audio,presence,backup,sleepmode}.service: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
    [crash_notify.py, db.py, test_crash_notify.py]
2026-06-10 docs: add ADR-011 enclosure design decisions
2026-06-11 Create enclosure
2026-06-11 Update and rename enclosure.md to enclosure-readme.md
2026-06-12 v4 enclosure: archive v3 files, add validate.py, rewrite enclosure README for v4 dimensions and magnetic lid
    [basecamp_body_v3.step, basecamp_body_v3.stl, basecamp_lid_v3.step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]
2026-06-12 v4 enclosure: add ADR-012 covering magnetic lid, hub deletion, and hotspot networking decisions
2026-06-12 v4 enclosure: update BOM -- delete hub, add DS3231 RTC, magnets, RGB LED, 20AWG Node 2 cable, v4 print cost
2026-06-12 v4 enclosure: update assembly bring-up guide -- magnet assembly, DS3231 RTC, node power from Pi USB, hotspot networking
2026-06-12 v4 enclosure: add docs/sensor-notes.md with v4 ventilation flow, DS3231 RTC timekeeping, mic funnel notes
2026-06-12 v4 enclosure: software updates -- hotspot-canonical pi_setup.sh, DS3231 RTC, glow LED, screen auto-wake, undervoltage check, networking docs, tests
2026-06-12 v4 enclosure: update README hardware summary -- magnetic lid, hotspot-first networking, DS3231 RTC
